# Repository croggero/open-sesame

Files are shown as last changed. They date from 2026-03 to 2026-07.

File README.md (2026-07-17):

# Open Sesame

ESP32-S3 firmware (Rust + esp-idf) for an assistive sliding door controller.

## Features

- Velocity-based assistive open/close
- Auto end-stop calibration and optional close-side homing
- Stall detection (obstacle / end-stop)
- Home Assistant MQTT discovery; commands, state and telemetry topics
- Captive-portal provisioning, factory reset via GPIO 0
- Build-time hardware/tuning configuration in `config.toml`

## Hardware

- ESP32-S3
- DRV8874 H-bridge (PhEn or InIn mode, set in `config.toml`)
- Quadrature encoder on the door drive
- Status LED, factory-reset button, optional toggle button

Pin assignments live under `[pins]` in `config.toml`.

## Building

Requires the Espressif Rust toolchain. See https://docs.esp-rs.org/book/installation/ for setup details.

1. Install `espup` and the `esp` toolchain:
   ```bash
   cargo install espup
   espup install
   ```
2. Source the export script in your shell (path printed by `espup install`):
   ```bash
   . $HOME/export-esp.sh
   ```
3. Install the flashing tools:
   ```bash
   cargo install espflash ldproxy
   ```
4. Edit `config.toml` to match your hardware (pins, motor mode, tuning).
5. Build:
   ```bash
   cargo build --release
   ```
6. Flash a connected ESP32 and open a serial monitor:
   ```bash
   cargo run --release
   ```
   Or, to flash with probe-rs and attach a debugger:
   ```bash
   cargo embed --release
   ```
  Or
  ```bash
  cargo flash --release --chip esp32s3
  ```

## First boot

1. Power the board. The status LED flashes to indicate the captive portal is active.
2. Connect to the `Open Sesame` SoftAP from a phone or laptop.
3. Submit WiFi and MQTT credentials in the provisioning form. The device reboots and connects.
4. The door is now visible in Home Assistant via MQTT discovery.

To re-provision, hold the factory-reset button (GPIO 0) for 5 seconds.

## Layout

- `src/main.rs` — boot sequence and control loop
- `src/door_controller.rs` — state machine, calibration, stall handling
- `src/motor.rs` — DRV8874 PWM driver (LEDC, 20 kHz)
- `src/encoder.rs` — PCNT quadrature decoder with 32-bit overflow tracking
- `src/mqtt_client.rs` — MQTT wrapper and command thread
- `src/captive_portal.rs` — SoftAP + HTTP provisioning
- `src/config.rs` — NVS-backed runtime config and build-time constants
- `config.toml` — hardware and tuning constants, parsed by `build.rs`

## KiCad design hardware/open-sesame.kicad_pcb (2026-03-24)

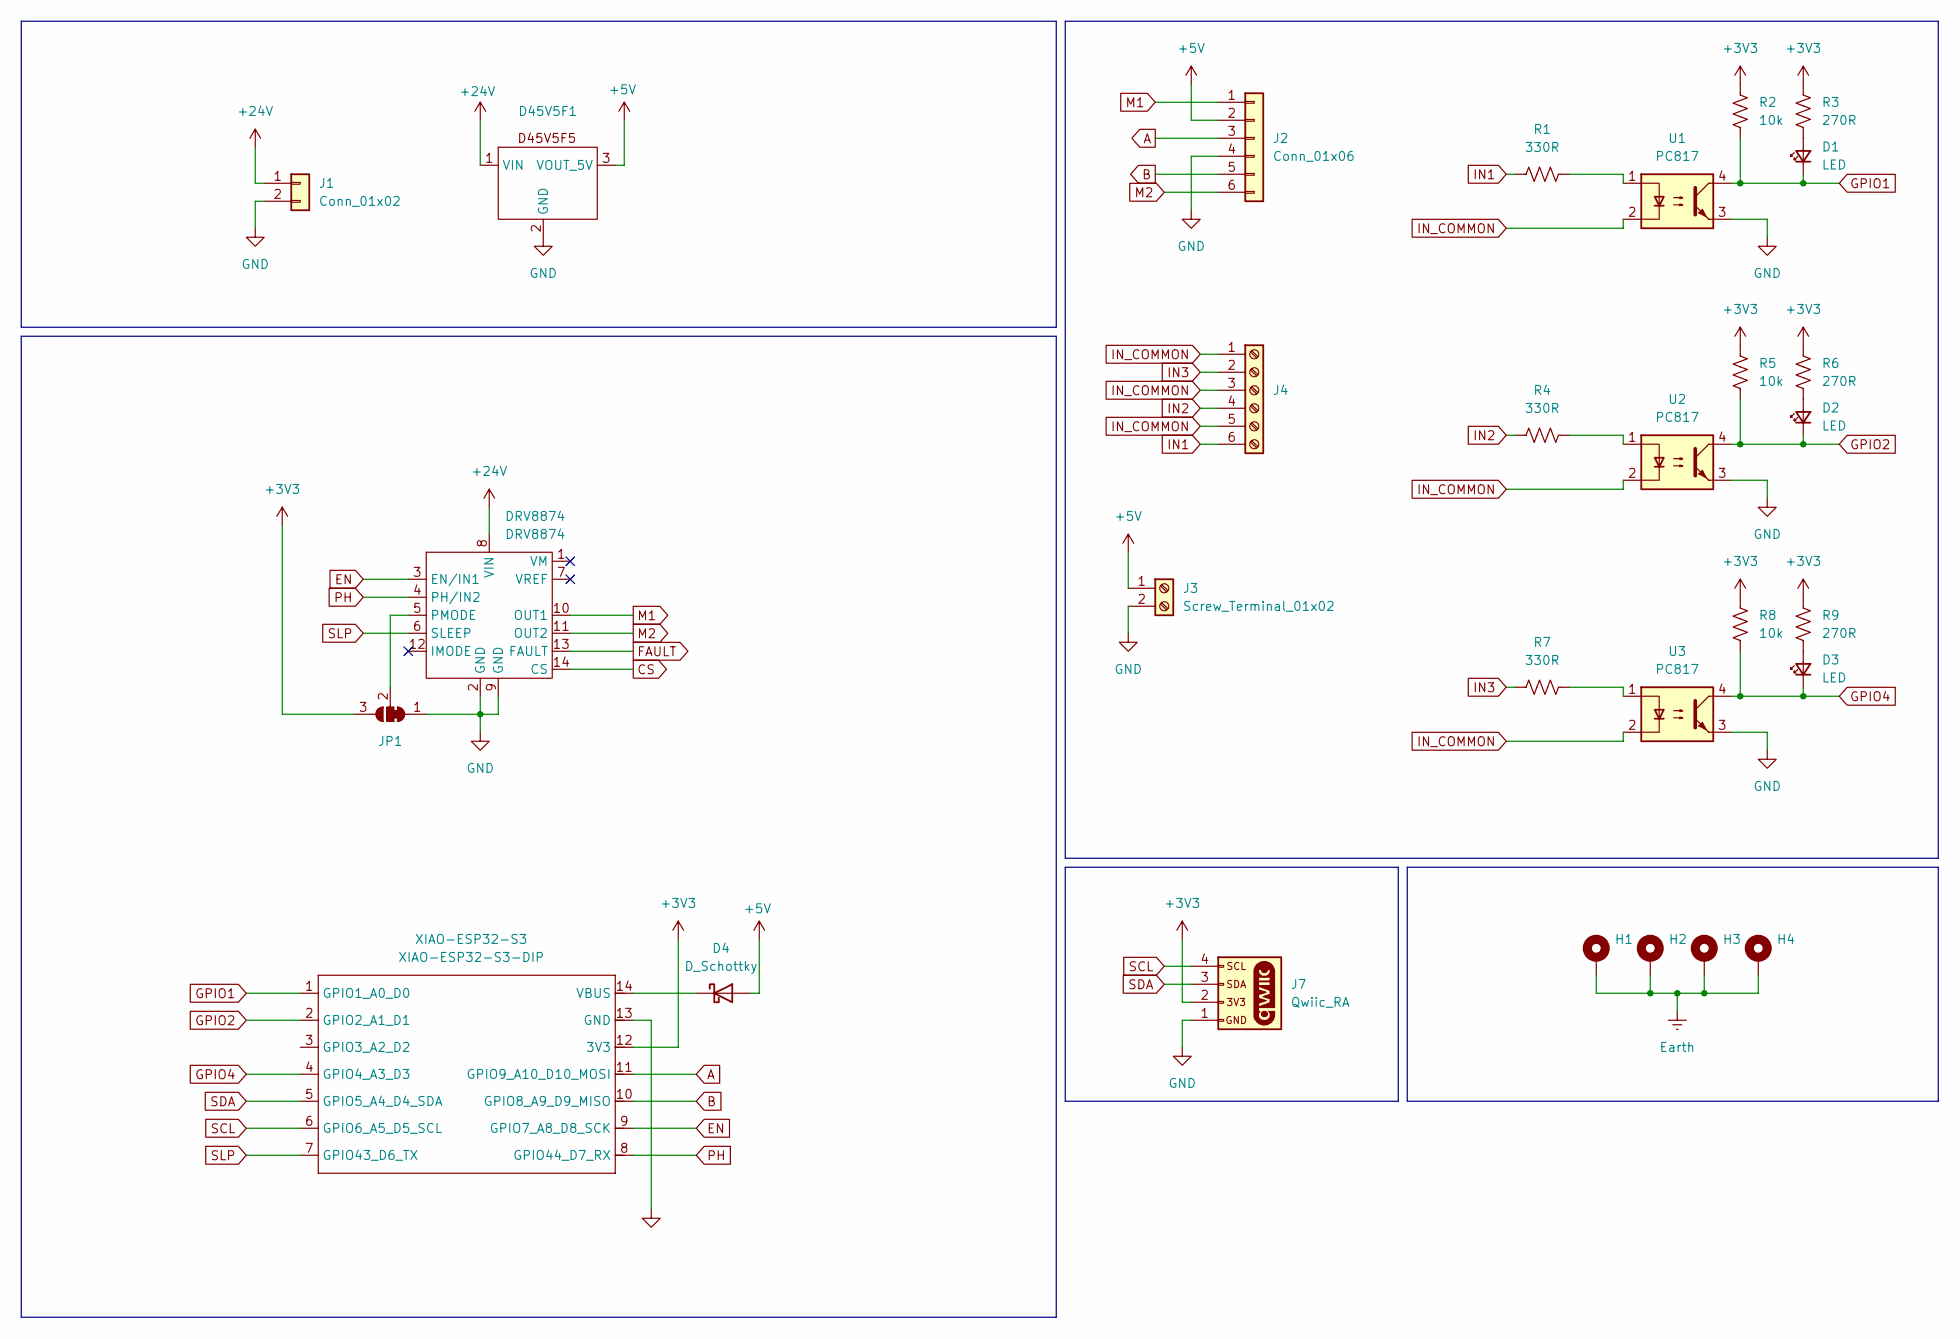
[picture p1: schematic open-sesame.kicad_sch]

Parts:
D1, D2, D3: LED; LED_0603_1608Metric
D4: D_Schottky; D_0603_1608Metric_Pad1.05x0.95mm_HandSolder
D45V5F1: D45V5F5; D45V5Fx
DRV8874: DRV8874
H1, H2, H3, H4: MountingHole_Pad; MountingHole_2.5mm_Pad_Via
J1: Conn_01x02; Molex_Nano-Fit_105313-xx02_1x02_P2.50mm_Horizontal
J2: Conn_01x06; Molex_Nano-Fit_105313-xx06_1x06_P2.50mm_Horizontal
J3: Screw_Terminal_01x02; TerminalBlock_Phoenix_MPT-0,5-2-2.54_1x02_P2.54mm_Horizontal
J4: Screw_Terminal_01x06; TerminalBlock_Phoenix_MPT-0,5-6-2.54_1x06_P2.54mm_Horizontal
J7: Qwiic_RA; JST_1x04_P1.0mm_Horizontal_SMD
JP1: SolderJumper_3_Bridged12; SolderJumper-3_P1.3mm_Bridged2Bar12_Pad1.0x1.5mm
R1, R4, R7: 330R; R_0603_1608Metric
R2, R5, R8: 10k; R_0603_1608Metric
R3, R6, R9: 270R; R_0603_1608Metric
U1, U2, U3: PC817; DIP-4_W7.62mm
XIAO-ESP32-S3: XIAO-ESP32-S3-DIP

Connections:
+3V3: J7.2, JP1.3 (B), R2.1, R3.1, R5.1, R6.1, R8.1, R9.1, XIAO-ESP32-S3.12 (3V3)
+5V: D4.2 (A), D45V5F1.3 (VOUT_5V), J2.2, J3.1
+24V: D45V5F1.1 (VIN), DRV8874.8 (VIN), J1.1
A: J2.3, XIAO-ESP32-S3.11 (GPIO9_A10_D10_MOSI)
B: J2.5, XIAO-ESP32-S3.10 (GPIO8_A9_D9_MISO)
CS: DRV8874.14 (CS)
EN: DRV8874.3 (EN/IN1), XIAO-ESP32-S3.9 (GPIO7_A8_D8_SCK)
Earth: H1.1, H2.1, H3.1, H4.1
FAULT: DRV8874.13 (FAULT)
GND: D45V5F1.2 (GND), DRV8874.2 (GND), DRV8874.9 (GND), J1.2, J2.4, J3.2, J7.1, JP1.1 (A), U1.3, U2.3, U3.3, XIAO-ESP32-S3.13 (GND)
GPIO1: D1.1 (K), R2.2, U1.4, XIAO-ESP32-S3.1 (GPIO1_A0_D0)
GPIO2: D2.1 (K), R5.2, U2.4, XIAO-ESP32-S3.2 (GPIO2_A1_D1)
GPIO4: D3.1 (K), R8.2, U3.4, XIAO-ESP32-S3.4 (GPIO4_A3_D3)
IN1: J4.6, R1.1
IN2: J4.4, R4.1
IN3: J4.2, R7.1
IN_COMMON: J4.1, J4.3, J4.5, U1.2, U2.2, U3.2
M1: DRV8874.10 (OUT1), J2.1
M2: DRV8874.11 (OUT2), J2.6
unnamed: D1.2 (A), R3.2
unnamed: D2.2 (A), R6.2
unnamed: D3.2 (A), R9.2
unnamed: D4.1 (K), XIAO-ESP32-S3.14 (VBUS)
unnamed: DRV8874.5 (PMODE), JP1.2 (C)
unnamed: R1.2, U1.1
unnamed: R4.2, U2.1
unnamed: R7.2, U3.1
PH: DRV8874.4 (PH/IN2), XIAO-ESP32-S3.8 (GPIO44_D7_RX)
SCL: J7.4, XIAO-ESP32-S3.6 (GPIO6_A5_D5_SCL)
SDA: J7.3, XIAO-ESP32-S3.5 (GPIO5_A4_D4_SDA)
SLP: DRV8874.6 (SLEEP), XIAO-ESP32-S3.7 (GPIO43_D6_TX)

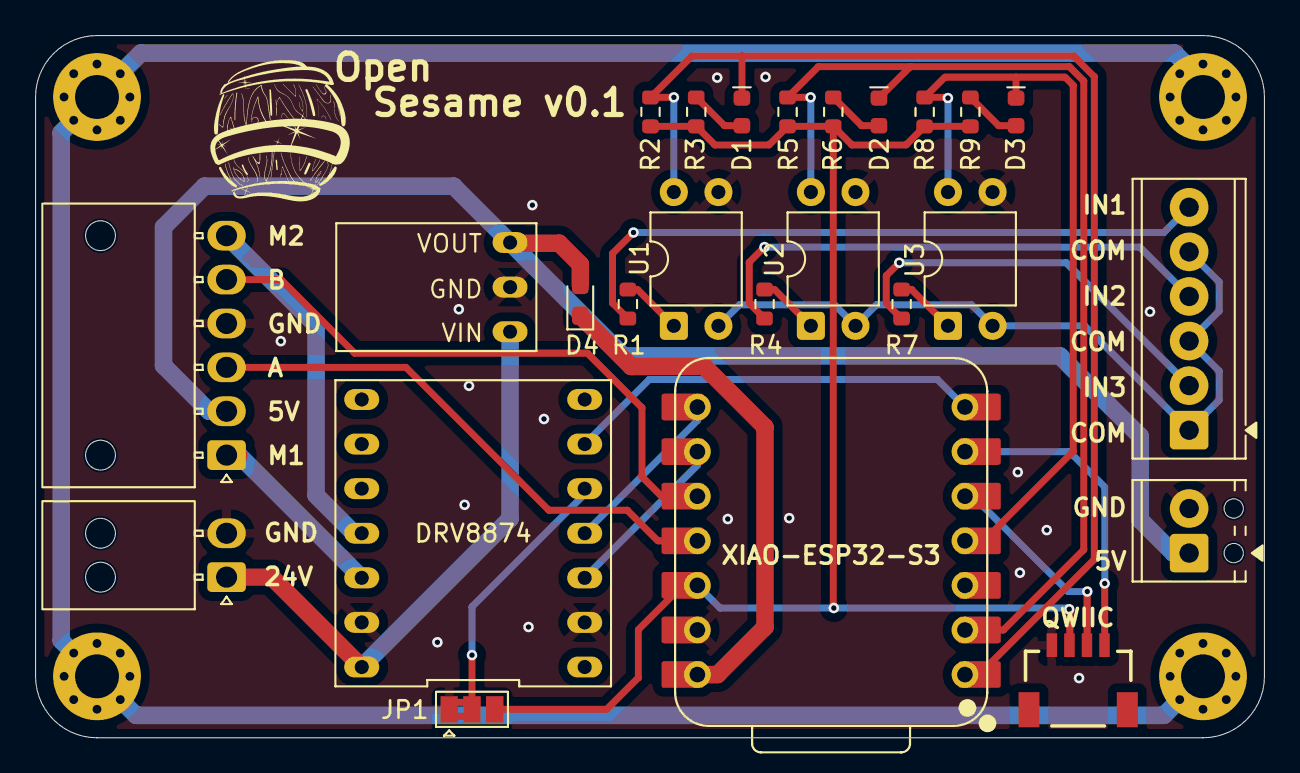
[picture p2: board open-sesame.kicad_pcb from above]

Board: 2 copper layers, 70.0 x 40.0 mm, 29 parts (0 on the bottom side), 29 nets.

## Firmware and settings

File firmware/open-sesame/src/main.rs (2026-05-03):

// src/main.rs
//
// Open Sesame Door Controller
//
// Boot sequence:
//   1. Check factory-reset button (GPIO 0, hold 5 s)
//   2. Load config from NVS
//   3. If no config → run captive portal, save, reboot
//   4. Connect WiFi → connect MQTT → publish HA discovery
//   5. Start assistive door control loop on this thread
//   6. On MQTT config/set message → save new config, reboot
//
// Pin map — see src/pins.rs to remap all GPIO assignments.

use anyhow::Result;
use esp_idf_hal::{
    gpio::{AnyIOPin, AnyInputPin, AnyOutputPin, PinDriver, Pull},
    peripherals::Peripherals,
};
use esp_idf_svc::{
    eventloop::EspSystemEventLoop,
    mdns::EspMdns,
    nvs::{EspDefaultNvsPartition, EspNvs, NvsDefault},
    wifi::{BlockingWifi, ClientConfiguration, Configuration, EspWifi},
};
use log::{info, warn};
use std::time::Duration;

mod captive_portal;
mod config;
mod door_controller;
mod encoder;
mod motor;
mod mqtt_client;

use captive_portal::{needs_provisioning, run_captive_portal};
use config::Config;
use door_controller::{DoorController, DoorState};
use encoder::Encoder;
use motor::MotorDriver;
use mqtt_client::{json_str_field, MqttCommand, MqttHandle};

// ─────────────────────────────────────────────────────────────────────────────
// Entry point
// ─────────────────────────────────────────────────────────────────────────────

fn main() -> Result<()> {
    // Required by esp-idf-svc — patches std hooks
    esp_idf_svc::sys::link_patches();

    // Initialise the ESP-IDF logger (output via UART0 / USB-JTAG)
    esp_idf_svc::log::EspLogger::initialize_default();

    // Door control must outrank app threads (mqtt-tx, mqtt-rx, wifi-mon all
    // default to 5). Stay below WiFi (23) / esp_timer (22) / LWIP (18) so the
    // radio and timer dispatch keep running.
    unsafe {
        esp_idf_svc::sys::vTaskPrioritySet(std::ptr::null_mut(), 10);
    }

    info!("=== Open Sesame booting ===");

    let peripherals = Peripherals::take()?;
    let sysloop = EspSystemEventLoop::take()?;
    let nvs_partition = EspDefaultNvsPartition::take()?;

    // Open (or create) our NVS namespace
    let mut nvs: EspNvs<NvsDefault> = EspNvs::new(nvs_partition.clone(), "door_cfg", true)?;

    // ── Status LED (on at boot) ─────────────────────────────────────────────
    let mut led = PinDriver::output(unsafe { AnyIOPin::new(config::PIN_LED) })?;
    led.set_low()?;

    // ── Factory reset ─────────────────────────────────────────────────────────
    {
        let mut reset_btn = PinDriver::input(unsafe { AnyIOPin::new(config::PIN_FACTORY_RESET) })?;
        reset_btn.set_pull(Pull::Up)?;

        if reset_btn.is_low() {
            info!("Reset button held — waiting 5 s for factory reset confirmation...");
            std::thread::sleep(Duration::from_secs(5));
            if reset_btn.is_low() {
                info!("Factory reset triggered! Erasing config.");
                Config::erase(&mut nvs)?;
                info!("Config erased. Restarting into captive portal...");
                std::thread::sleep(Duration::from_millis(200));
                esp_idf_hal::reset::restart();
            }
            info!("Button released — skipping factory reset.");
        }
    }

    // ── Provisioning ──────────────────────────────────────────────────────────
    if needs_provisioning(&nvs) {
        info!("No config found — starting captive portal.");

        // Flash LED in a background thread while provisioning
        let flash_active = std::sync::Arc::new(std::sync::atomic::AtomicBool::new(true));
        let flash_flag = flash_active.clone();
        std::thread::spawn(move || {
            while flash_flag.load(std::sync::atomic::Ordering::Relaxed) {
                let _ = led.toggle();
                std::thread::sleep(Duration::from_millis(500));
            }
            let _ = led.set_high();
        });

        run_captive_portal(peripherals.modem, sysloop.clone(), &mut nvs)?;
        flash_active.store(false, std::sync::atomic::Ordering::Relaxed);

        info!("Config saved. Restarting...");
        std::thread::sleep(Duration::from_millis(500));
        esp_idf_hal::reset::restart();
    }

    let mut config = Config::load(&nvs);
    info!(
        "Config loaded: ssid={}, broker={}, opening_counts={}",
        config.wifi_ssid, config.mqtt_broker, config.opening_counts
    );

    // ── WiFi ──────────────────────────────────────────────────────────────────
    info!("Connecting to Wifi");
    let wifi = connect_wifi(peripherals.modem, sysloop.clone(), &config)?;
    info!("WiFi connected");

    // Hand ownership to a background monitor thread that auto-reconnects on drop.
    // The main control loop never touches wifi again — keeps door safety isolated.
    spawn_wifi_monitor(wifi);

    // Start mDNS so LWIP's DNS resolver can resolve *.local broker hostnames.
    // Bound to a variable kept alive for the program's lifetime — dropping it
    // would tear down the responder.
    let _mdns = EspMdns::take()?;

    // ── Toggle button ─────────────────────────────────────────────────────────
    let mut toggle_btn = PinDriver::input(unsafe { AnyIOPin::new(config::PIN_TOGGLE) })?;
    toggle_btn.set_pull(Pull::Up)?;
    let mut toggle_last_raw = toggle_btn.is_high(); // high = released (active-low)
    let mut toggle_debounce: u32 = 0;
    let mut toggle_pressed_prev = false;

    // ── Encoder (hardware PCNT) ─────────────────────────────────────────────
    info!("Initializing Encoder");
    let encoder = Encoder::new(
        peripherals.pcnt0,
        unsafe { AnyInputPin::new(config::PIN_ENC_A) },
        unsafe { AnyInputPin::new(config::PIN_ENC_B) },
    )?;

    // ── Motor driver ──────────────────────────────────────────────────────────
    info!("Initializing Motor Driver");
    let motor = MotorDriver::new(
        peripherals.ledc.timer0,
        peripherals.ledc.channel0,
        unsafe { AnyOutputPin::new(config::PIN_MOTOR_IN1) },
        unsafe { AnyOutputPin::new(config::PIN_MOTOR_IN2) },
        unsafe { AnyOutputPin::new(config::PIN_MOTOR_NSLP) },
        config::MOTOR_MODE,
    )?;

    // ── MQTT ──────────────────────────────────────────────────────────────────
    info!("Starting MQTT Client");
    let (mut mqtt, connection) = MqttHandle::connect(&config)?;
    let cmd_rx = mqtt.spawn_receive_thread(connection);

    // ── Door controller ───────────────────────────────────────────────────────
    info!("Starting Door Controller");
    let mut door = DoorController::new(motor, encoder);
    door.set_opening(config.opening_counts);

    // Drive to the closed endstop to establish encoder zero after power loss.
    door.start_homing()?;

    info!("Entering control loop");

    let mut tick_count: u32 = 0;

    loop {
        // ── Control tick ──────────────────────────────────────────────────────
        door.tick()?;

        // Save door opening if changed
        if door.opening() != config.opening_counts {
            config.opening_counts = door.opening();
            info!("Saving opening counts: {}", config.opening_counts);
            config.save(&mut nvs)?;
        }

        // ── Periodic state publish (state + position + velocity) ──────────────
        tick_count = tick_count.wrapping_add(1);
        if tick_count % config::TELEMETRY_TICKS == 0 {
            mqtt.publish_state(&door);
        }

        // ── Toggle button ─────────────────────────────────────────────────────
        {
            let raw = toggle_btn.is_high();
            if raw == toggle_last_raw {
                if toggle_debounce < config::BUTTON_DEBOUNCE_TICKS {
                    toggle_debounce += 1;
                }
            } else {
                toggle_last_raw = raw;
                toggle_debounce = 0;
            }

            // Stable low = button pressed; detect the falling edge
            let pressed = toggle_debounce >= config::BUTTON_DEBOUNCE_TICKS && !raw;
            if pressed && !toggle_pressed_prev {
                match door.state() {
                    DoorState::Open | DoorState::Opening => door.drive_close()?,
                    _ => door.drive_open()?,
                }
            }
            toggle_pressed_prev = pressed;
        }

        // ── MQTT commands ─────────────────────────────────────────────────────
        if let Ok(cmd) = cmd_rx.try_recv() {
            match cmd {
                MqttCommand::Connected => {
                    info!("MQTT connected — subscribing and publishing discovery");
                    mqtt.subscribe_commands()?;
                    mqtt.publish_ha_discovery(&config.mqtt_client_id);
                }
                MqttCommand::ConfigUpdate(json) => {
                    info!("Remote config update received: {}", json);
                    apply_remote_config(&json, &mut nvs)?;
                    info!("New config saved. Restarting...");
                    std::thread::sleep(Duration::from_millis(500));
                    esp_idf_hal::reset::restart();
                }
                MqttCommand::Position(pos) => door.set_position(pos)?,
                MqttCommand::Open => door.drive_open()?,
                MqttCommand::Close => door.drive_close()?,
                MqttCommand::Stop => door.stop()?,
                MqttCommand::Calibrate => {
                    info!("Calibration requested via MQTT");
                    door.start_calibrate()?;
                }
                MqttCommand::Home => {
                    info!("Home requested via MQTT");
                    door.start_homing()?;
                }
            }
        }

        std::thread::sleep(DoorController::loop_period());
    }
}

// ─────────────────────────────────────────────────────────────────────────────
// WiFi helper
// ─────────────────────────────────────────────────────────────────────────────

fn connect_wifi(
    modem: impl esp_idf_hal::peripheral::Peripheral<P = esp_idf_hal::modem::Modem> + 'static,
    sysloop: EspSystemEventLoop,
    cfg: &Config,
) -> Result<BlockingWifi<EspWifi<'static>>> {
    let mut wifi = BlockingWifi::wrap(EspWifi::new(modem, sysloop.clone(), None)?, sysloop)?;

    wifi.set_configuration(&Configuration::Client(ClientConfiguration {
        ssid: cfg
            .wifi_ssid
            .as_str()
            .try_into()
            .map_err(|_| anyhow::anyhow!("SSID too long"))?,
        password: cfg
            .wifi_password
            .as_str()
            .try_into()
            .map_err(|_| anyhow::anyhow!("WiFi password too long"))?,
        ..Default::default()
    }))?;

    wifi.start()?;

    // Retry up to 3 times before giving up and launching the captive portal
    for attempt in 1..=3 {
        info!("WiFi connect attempt {attempt}/3...");
        match wifi.connect() {
            Ok(_) => break,
            Err(e) if attempt == 3 => {
                return Err(anyhow::anyhow!("WiFi failed after 3 attempts: {:?}", e));
            }
            Err(e) => {
                warn_wifi(e);
                std::thread::sleep(Duration::from_secs(2));
            }
        }
    }

    wifi.wait_netif_up()?;
    Ok(wifi)
}

fn warn_wifi(e: impl std::fmt::Debug) {
    warn!("WiFi connect error: {:?}", e);
}

/// Background thread that watches the WiFi link and reconnects on drop.
///
/// Runs on its own thread so a reconnect storm (which can block for many
/// seconds inside `wifi.connect()`) cannot stall the safety-critical door
/// control loop. MQTT auto-reconnects on its own once WiFi is back, and the
/// existing `MqttCommand::Connected` path re-subscribes + re-publishes HA
/// discovery.
fn spawn_wifi_monitor(mut wifi: BlockingWifi<EspWifi<'static>>) {
    std::thread::Builder::new()
        .name("wifi-mon".into())
        .stack_size(8192)
        .spawn(move || loop {
            std::thread::sleep(Duration::from_secs(5));

            if matches!(wifi.is_connected(), Ok(true)) {
                continue;
            }

            warn!("WiFi link down — attempting reconnect");
            let mut backoff = Duration::from_secs(2);
            loop {
                match wifi.connect().and_then(|_| wifi.wait_netif_up()) {
                    Ok(_) => {
                        info!("WiFi reconnected");
                        break;
                    }
                    Err(e) => {
                        warn!("WiFi reconnect failed: {:?} — retry in {:?}", e, backoff);
                        std::thread::sleep(backoff);
                        backoff = (backoff * 2).min(Duration::from_secs(30));
                    }
                }
            }
        })
        .expect("failed to spawn wifi-mon thread");
}

// ─────────────────────────────────────────────────────────────────────────────
// Remote config update via MQTT
// ─────────────────────────────────────────────────────────────────────────────

/// Parse a partial JSON config payload and update only the supplied keys.
///
/// Example payload:
/// ```json
/// {"mqtt_broker":"mqtt://192.168.1.200:1883","mqtt_id":"door-v2"}
/// ```
fn apply_remote_config(json: &str, nvs: &mut EspNvs<NvsDefault>) -> Result<()> {
    // Load current config so we don't overwrite fields not in the payload
    let mut cfg = Config::load(nvs);

    if let Some(v) = json_str_field(json, "ssid") {
        cfg.wifi_ssid = v.into();
    }
    if let Some(v) = json_str_field(json, "wifi_pass") {
        cfg.wifi_password = v.into();
    }
    if let Some(v) = json_str_field(json, "mqtt_broker") {
        cfg.mqtt_broker = v.into();
    }
    if let Some(v) = json_str_field(json, "mqtt_id") {
        cfg.mqtt_client_id = v.into();
    }
    if let Some(v) = json_str_field(json, "mqtt_user") {
        cfg.mqtt_username = v.into();
    }
    if let Some(v) = json_str_field(json, "mqtt_pass") {
        cfg.mqtt_password = v.into();
    }

    cfg.save(nvs)?;
    Ok(())
}

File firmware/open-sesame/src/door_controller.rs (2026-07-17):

// src/door_controller.rs
//
// Core assistive control loop for the sliding door.
//
// State machine:
//
//   Commands (open/close)
//   ┌─────────────────────────────────────────────────────────┐
//   │                                                         │
//   ▼                                                         │
//   ┌─────────┐  encoder moves > threshold  ┌──────────────┐ │
//   │  Idle   │ ─────────────────────────── │ Assist       │ │
//   │ (sleep) │ ◄──── timeout elapsed ───── │ (push/pull)  │ │
//   └─────────┘                             └──────┬───────┘ │
//        ▲                                         │         │
//        │ stop / endstop                          │ endstop │
//        │                                         ▼         │
//        └───────────────────────────────── ┌──────────────┐ │
//                                           │ Open/Closed  │─┘
//                                           └──────────────┘
//
// Remote drive (open/close command) overrides assist when a target is set.
// Endstops always take priority and clear the door target.
//
// The control loop runs at ~10 ms intervals on the calling thread.
// The encoder ISR updates position atomically from a separate context.

use crate::config;
use crate::encoder::Encoder;
use crate::motor::MotorDriver;
use anyhow::{Ok, Result};
use log::info;
use std::time::{Duration, Instant};

// All tuning constants live in config.toml and are exposed via crate::config.
use config::{
    ASSIST_LOCKOUT_TICKS, ASSIST_VELOCITY_THRESHOLD, CALIBRATE_POWER, CALIBRATION_PAUSE_TICKS,
    CALIBRATION_STALL_TICKS, CALIBRATION_TIMEOUT_TICKS, CLOSED_THRESHOLD, CLOSE_HOMING, DEAD_ZONE,
    IDLE_TIMEOUT_MS, INVERT_DIRECTION, LOOP_PERIOD_MS, LPF_ALPHA, OPERATING_POWER,
    RAMP_DOWN_COUNTS, REVERSAL_PAUSE_TICKS, SETTLE_TICKS, STALL_GRACE_TICKS, STALL_TICKS,
};

const IDLE_TIMEOUT: Duration = Duration::from_millis(IDLE_TIMEOUT_MS);
const LOOP_PERIOD: Duration = Duration::from_millis(LOOP_PERIOD_MS);

/// Returns 1 or -1 based on INVERT_DIRECTION.
const fn dir() -> i32 {
    if INVERT_DIRECTION {
        -1
    } else {
        1
    }
}

// ─────────────────────────────────────────────────────────────────────────────
// DoorState
// ─────────────────────────────────────────────────────────────────────────────

#[derive(Debug, Clone, PartialEq)]
pub enum DoorState {
    Idle,
    Stopping,
    Opening,
    Closing,
    Open,
    Closed,
    /// Boot-up homing: drive toward closed endstop, reset encoder, done.
    Homing {
        stall_count: u32,
        timeout_ticks: u32,
    },
    Calibrating,
}

impl DoorState {
    pub fn as_str(&self) -> &'static str {
        match self {
            DoorState::Idle => "idle",
            DoorState::Stopping => "stopping",
            DoorState::Opening => "opening",
            DoorState::Closing => "closing",
            DoorState::Open => "open",
            DoorState::Closed => "closed",
            DoorState::Homing {
                stall_count: _,
                timeout_ticks: _,
            } => "homing",
            DoorState::Calibrating => "calibrating",
        }
    }
}

// ─────────────────────────────────────────────────────────────────────────────
// CalibrationStep
// ─────────────────────────────────────────────────────────────────────────────

/// Tracks progress through the non-blocking calibration sequence.
enum CalibrationStep {
    /// Driving toward the closed endstop; counting consecutive no-motion ticks.
    DrivingClosed {
        stall_count: u32,
        timeout_ticks: u32,
    },
    /// Brief pause between directions (ticks remaining).
    Pause { remaining: u32 },
    /// Driving toward the open endstop; counting consecutive no-motion ticks.
    DrivingOpen {
        stall_count: u32,
        timeout_ticks: u32,
    },
}

// ─────────────────────────────────────────────────────────────────────────────
// DoorController
// ─────────────────────────────────────────────────────────────────────────────

pub struct DoorController<'d, 'e> {
    motor: MotorDriver<'d>,
    encoder: Encoder<'e>,
    state: DoorState,
    last_pos: i32,
    velocity: f32,
    last_move_time: Instant,
    target: Option<i32>,
    opening_counts: i32,
    /// Active calibration step, or None when not calibrating.
    calibration: Option<CalibrationStep>,
    /// Consecutive no-motion ticks while motor is powered (obstacle detection).
    obstacle_stall_count: u32,
    /// Ticks since the current target was set. Stall detection is suppressed
    /// until this exceeds STALL_GRACE_TICKS.
    drive_ticks: u32,
    /// Ticks remaining before assist re-arms. Non-zero after an obstacle stop.
    assist_lockout: u32,
    /// Consecutive stationary ticks accumulated in the Stopping state.
    settle_count: u32,
    /// Target to adopt once the door has coasted to a stop, set when a command
    /// asks a moving door to reverse.
    pending_target: Option<i32>,
}
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

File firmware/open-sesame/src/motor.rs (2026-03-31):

// src/motor.rs
//
// Abstraction over the DRV8874 H-bridge motor driver.
//
// The DRV8874 supports two control modes selected by the hardware MODE pin:
//
//   IN/IN mode  (MODE = LOW):
//     Forward : IN1 = PWM,  IN2 = LOW   → variable speed
//     Reverse : IN1 = LOW,  IN2 = PWM   → requires second LEDC channel; we only
//               have one, so reverse is full-power only (IN2 = HIGH).
//     Brake   : IN1 = HIGH, IN2 = HIGH  (active brake via high-side + low-side)
//     Coast   : nSLP = LOW
//
//   PH/EN mode  (MODE = HIGH):
//     Forward : PH = HIGH, EN = PWM     → variable speed
//     Reverse : PH = LOW,  EN = PWM     → variable speed (advantage over IN/IN)
//     Brake   : EN = LOW,  nSLP = HIGH  (both low-side FETs on, motor shorted)
//     Coast   : nSLP = LOW
//
// Pin assignments — see src/pins.rs:
//   IN1 / EN  → PIN_MOTOR_IN1  (LEDC PWM channel 0)
//   IN2 / PH  → PIN_MOTOR_IN2  (digital output)
//   nSLP      → PIN_MOTOR_NSLP (active-high enable)

use anyhow::Result;
use esp_idf_hal::{
    gpio::{Output, PinDriver},
    ledc::{
        config::TimerConfig, LedcChannel, LedcDriver, LedcTimer, LedcTimerDriver, Resolution,
        SpeedMode,
    },
    peripheral::Peripheral,
    prelude::*,
};

use crate::config;

// ─────────────────────────────────────────────────────────────────────────────
// MotorMode
// ─────────────────────────────────────────────────────────────────────────────

/// Selects which DRV8874 control mode the hardware MODE pin is wired for.
#[derive(Clone, Copy)]
#[allow(dead_code)]
pub enum MotorMode {
    /// IN/IN mode (MODE pin LOW). Variable-speed forward only; reverse is
    /// full-power (single LEDC channel limitation).
    InIn,
    /// PH/EN mode (MODE pin HIGH). Variable speed in both directions.
    PhEn,
}

// ─────────────────────────────────────────────────────────────────────────────
// MotorDriver
// ─────────────────────────────────────────────────────────────────────────────

pub struct MotorDriver<'d> {
    pwm: LedcDriver<'d>, // IN1 (IN/IN) or EN (PH/EN)
    in2: PinDriver<'d, esp_idf_hal::gpio::AnyOutputPin, Output>, // IN2 or PH
    nslp: PinDriver<'d, esp_idf_hal::gpio::AnyOutputPin, Output>,
    mode: MotorMode,
    awake: bool,
}

impl<'d> MotorDriver<'d> {
    pub fn new<S: SpeedMode>(
        timer: impl Peripheral<P: LedcTimer<SpeedMode = S>> + 'd,
        channel: impl Peripheral<P: LedcChannel<SpeedMode = S>> + 'd,
        pin_in1: impl Peripheral<P: esp_idf_hal::gpio::OutputPin> + 'd,
        pin_in2: impl Peripheral<P: esp_idf_hal::gpio::OutputPin> + 'd,
        pin_nslp: impl Peripheral<P: esp_idf_hal::gpio::OutputPin> + 'd,
        mode: MotorMode,
    ) -> Result<Self> {
        let timer_cfg = TimerConfig::default()
            .frequency(config::PWM_FREQ_HZ.Hz().into())
            .resolution(Resolution::Bits8);

        let timer_drv = LedcTimerDriver::new(timer, &timer_cfg)?;
        let pwm = LedcDriver::new(channel, &timer_drv, pin_in1)?;
        let in2 = PinDriver::output(pin_in2.into_ref().map_into())?;
        let nslp = PinDriver::output(pin_nslp.into_ref().map_into())?;

        let mut drv = Self {
            pwm,
            in2,
            nslp,
            mode,
            awake: false,
        };
        drv.sleep()?;
        Ok(drv)
    }

    // ── Power control ─────────────────────────────────────────────────────────

    /// Wake the driver (nSLP HIGH). Must be called before setting speed.
    pub fn wake(&mut self) -> Result<()> {
        if !self.awake {
            self.nslp.set_high()?;
            // DRV8874 needs ~1 ms after nSLP goes high before accepting commands
            std::thread::sleep(std::time::Duration::from_millis(1));
            self.awake = true;
        }
        Ok(())
    }

    /// Put the driver into coast/sleep mode (nSLP LOW).
    pub fn sleep(&mut self) -> Result<()> {
        self.pwm.set_duty(0)?;
        self.in2.set_low()?;
        self.nslp.set_low()?;
        self.awake = false;
        Ok(())
    }

    // ── Motion ────────────────────────────────────────────────────────────────

    /// Set motor output. `power` in [-config::MAX_DUTY, config::MAX_DUTY].
    /// Positive = forward, negative = reverse, 0 = active brake.
    /// Non-zero values below MIN_POWER are clamped up to MIN_POWER.
    pub fn set_power(&mut self, power: i32) -> Result<()> {
        let max = config::MAX_DUTY as i32;

        let power = match power.clamp(-max, max) {
            p if p > 0 => p.max(config::MIN_DUTY),
            p if p < 0 => p.min(-config::MIN_DUTY),
            p => p,
        };

        match self.mode {
            MotorMode::InIn => self.set_power_inin(power),
            MotorMode::PhEn => self.set_power_phen(power),
        }
    }

    pub fn get_power(&self) -> i32 {
        let power = self.pwm.get_duty();
        let is_high = self.in2.is_set_high();

        (power as i32) * if is_high { 1 } else { -1 }
    }

    /// Convenience: active brake.
    pub fn brake(&mut self) -> Result<()> {
        self.set_power(0)
    }

    pub fn is_awake(&self) -> bool {
        self.awake
    }

    // ── Mode-specific helpers ─────────────────────────────────────────────────

    fn set_power_inin(&mut self, power: i32) -> Result<()> {
        if power == 0 {
            // Brake: IN1 = HIGH, IN2 = HIGH
            self.pwm.set_duty(config::MAX_DUTY)?;
            self.in2.set_high()?;
        } else if power > 0 {
            // Forward: IN1 = PWM, IN2 = LOW
            self.in2.set_low()?;
            self.pwm.set_duty(power as u32)?;
        } else {
            // Reverse: IN1 = LOW, IN2 = HIGH (full-power only — single LEDC limitation)
            self.pwm.set_duty(0)?;
            self.in2.set_high()?;
        }
        Ok(())
    }

    fn set_power_phen(&mut self, power: i32) -> Result<()> {
        if power == 0 {
            // Brake: EN = LOW, nSLP stays HIGH (both low-side FETs on)
            //self.pwm.set_duty(0)?

            self.in2.set_low()?;
            self.pwm.set_duty(0)?;
        } else if power > 0 {
            // Forward: PH = HIGH, EN = PWM
            self.in2.set_high()?;
            self.pwm.set_duty(power as u32)?;
        } else {
            // Reverse: PH = LOW, EN = PWM  (variable speed — PH/EN advantage)
            self.in2.set_low()?;
            self.pwm.set_duty(power.abs() as u32)?;
        }
        Ok(())
    }
}

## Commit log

2026-02-05 Initial hardware circuit
    [open-sesame.kicad_pcb, open-sesame.kicad_sch]
2026-02-05 Updated 3V & GND to terminal block
    [open-sesame.kicad_pcb, open-sesame.kicad_sch]
2026-02-05 fix(hardware): Corrected VIN&VOUT
    [open-sesame.kicad_pcb, open-sesame.kicad_sch]
2026-02-25 User Terminals, Added Optocoupler, Added QWIIC connector
    [open-sesame.kicad_pcb, open-sesame.kicad_sch]
2026-02-25 Use 2x 6 port connectors
    [open-sesame.kicad_pcb, open-sesame.kicad_sch]
2026-02-28 hardware: Use ESP32S3 for PCNT,
    [open-sesame.kicad_pcb, open-sesame.kicad_sch]
2026-03-02 hardware: shrunk board
    [open-sesame.kicad_pcb, open-sesame.kicad_sch]
2026-03-06 hardware: Use screw connectors and PC817
    [open-sesame.kicad_pcb, open-sesame.kicad_sch]
2026-03-24 hardware: use one power converter, shrink size, change connectors
    [open-sesame.kicad_pcb, open-sesame.kicad_sch]
2026-03-31 firmware: Added calibration, obstacle stall detection, HA discovery, toggle pin
    [door_controller.rs, main.rs, motor.rs]
2026-03-31 firmware: fix invert direction, added homing, save opening counts
    [door_controller.rs, main.rs]
2026-04-02 firmware: added homing, adjusted parameters, closed threshold
2026-05-03 firmware: mDNS support, MQTT publish thread separation, Wifi auto reconnect.
2026-07-17 fix: Recoil issue solved, Stalls when not moved at all during opening.
    [door_controller.rs]
2026-07-17 fix: Smooth motion transitions.
    [door_controller.rs]
